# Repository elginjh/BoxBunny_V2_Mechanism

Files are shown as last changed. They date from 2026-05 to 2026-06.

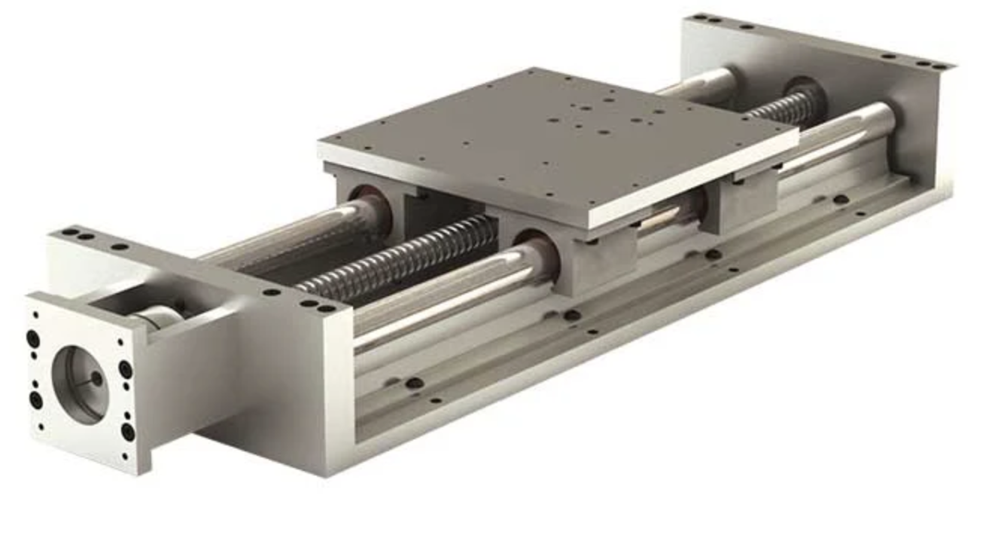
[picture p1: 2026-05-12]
CAD Model/Interim/Sub Assembly/Bottom/Renders/Movement/Ball Screw Driven Linear Rail.png

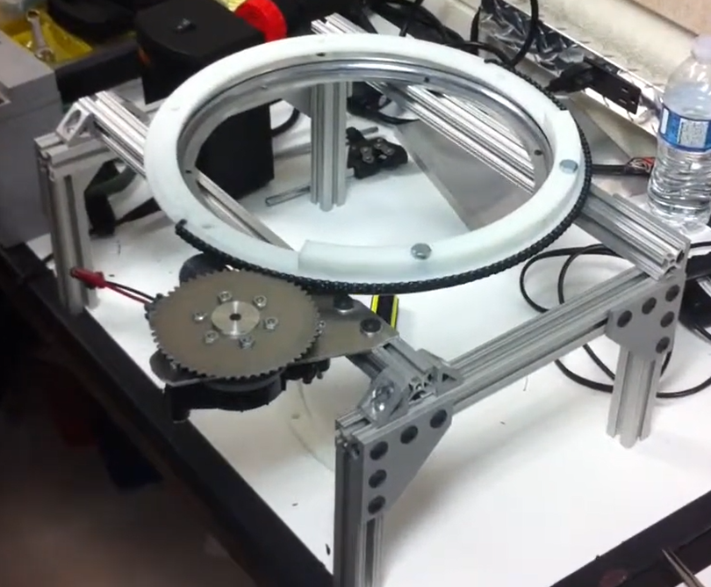
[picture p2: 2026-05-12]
CAD Model/Interim/Sub Assembly/Bottom/Renders/Movement/Lazy Susan Build.png

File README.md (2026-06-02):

# BoxBunny V2 Mechanism: Project Handover Documentation

This document serves as the formal handover reference for the BoxBunny V2 Mechanism repository. It details the directory structure, critical design rationales, and essential system configurations required for subsequent development phases.

## 1. Directory Structure and Repository Navigation

### 1.1 Electrical and Firmware (`ARM_ELECTRICAL_HANDOFF/`)
This directory contains critical documentation and codebase for the control systems, firmware, and electrical routing.
- **`KNOWN_ISSUES_HANDOFF.md`**: Mandatory reading prior to system operation. It documents active hardware and electrical limitations (e.g., ODrive Regen Clamp resistor sizing, 3D printed gear structural limits) and historical defect resolutions to prevent regression. It also outlines essential architectural behaviors, such as Joint-Space Pitch Clamping and "Tactical Walking".
- **`teensy_firmware_V5/`**: Contains the production Teensy 4.0 firmware used for the 200 Hz control loop, CAN bus communication with Damiao motors, and I²C MPU6050 polling. Refer to the internal `README.md` for pin assignments, ROS 2 topics, and micro-ROS payload layouts.

### 1.2 Mechanical Design and CAD Models (`CAD Model/`)
Contains the physical design files and sub-assemblies for the BoxBunny mechanism.
- **`Final/FINAL ASSEM/`**: The primary directory for the overall CAD. Contains the full, latest assembly file (`FINAL ASSEM.asm`), systematically structured into subfolders corresponding to the various subsystems.
- **`Final/Bottom Assembly/v7_fab/`**: Contains the latest production bottom assembly files, logically organized into individual subfolders. The nested `report/` directory contains HTML documentation (`concept-generation.html`, `lift-structure-separation.html`) detailing the engineering rationale for the height adjustment subsystem.
- **`Interim/`**: Contains deprecated V2 iterations and reference sub-assemblies.
- *Note: Various `readme-and-terms-of-use-3d-cad-models.txt` files are included throughout this directory, providing licensing text for third-party COTS components sourced from PARTcommunity/3Dfindit.*

### 1.3 General Project Documentation and Reports (`General Project/`)
Contains legacy V1 project files, procurement details, and comprehensive engineering reports.
- **`Procurement/`**: Contains documentation for all purchased items claimed and selected for this project. Technical specifications are accessible via the provided purchase links or, if unavailable online, stored directly within the `additional tech specs` directory.
- **`Reports/Final Report/Handover - Lower Mechanism FINAL Detailed Reports/`**: Contains the comprehensive final engineering documentation detailing the design, analysis, and specifications for the height adjustment, rotation, and base mechanisms.
- **`Reports/Interim Report/report appendix b/jeanette appendix b.txt`**: A detailed text export of the engineering calculations and concept generation matrices. This is required reading for understanding:
  - **Upper Mechanism:** The justification for the 2DOF (pitch/yaw) actuator, including torque, inertia, and aerodynamic drag calculations for the training sticks.
  - **Lower Mechanism:** The rationale for decoupling the footwork motion into a linear rail (forward/backward) and a slewing bearing (rotation) over omnidirectional wheels, alongside motor sizing and selection matrices.
- **`V1 (EG3301R)/`**: Legacy files from the first iteration of the BoxBunny project.

## 2. Mandatory Pre-Operation Procedures

1. **Review Known Issues:** Prior to motor initialization, operators must review the ODrive Regen Clamp calibration procedures and I²C blocking mitigations detailed in `KNOWN_ISSUES_HANDOFF.md`.
2. **Firmware Verification:** Verify that the Teensy microcontroller is provisioned with **Firmware V5** (`teensy_firmware_V5.ino`). This build contains critical hardware I²C timeouts and failsafes for IMU disconnections to prevent uncontrolled motor oscillation.

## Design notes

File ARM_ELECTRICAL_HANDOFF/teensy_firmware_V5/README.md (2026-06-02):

# Teensy Firmware V5

**Target:** Teensy 4.0 | **IDE:** Arduino IDE + Teensyduino

## What's in this sketch

| Feature | Detail |
|---|---|
| Control loop | 200 Hz unified loop (5 ms period) |
| CAN bus | FlexCAN_T4, 1 Mbps, 4× Damiao DM-J4310-2EC (base IDs 0x01–0x04; command frames 0x101–0x104) |
| IMU | 4× MPU6050 over dual I²C bus (Wire + Wire1, 400 kHz) |
| Height motor | Cytron MDDS10 via PWM (Pin 3) + DIR (Pin 2) |
| ROS 2 | micro-ROS over USB; publishes 21-double `/motor_feedback` payload |

## Feedback payload layout

```
[0..3]  Motor positions (rad)
[4..7]  Motor currents (A)
[8]     CAN RX frame count
[9..20] IMU accel XYZ for each of 4 sensors (m/s²)
```

## Changelog

### V5 Release (I²C Blocking Fix & Failsafe)
- **Hardware I²C Timeouts:** Added `Wire.setWireTimeout(3000, true)` on both I²C buses to prevent the default blocking behavior. If an MPU6050 disconnects or hangs, the bus safely aborts the read after 3ms instead of freezing the 200Hz loop and starving the CAN bus.
- **Sensor State Failsafe:** Introduced a global `imu_healthy` flag that tracks consecutive sensor errors. If an IMU drops offline (e.g. `imu_err_count > 3`), the firmware actively triggers a software override that sets `motors_enabled = false`. This drops the robot into a safe limp state, preventing violent jitter caused by "garbage" 0-value sensor data.

### 2026-04-06 — IMU range fix
- **ACCEL_CONFIG** changed `0x00` (±2g) → `0x18` (±16g)  
- **Conversion divisor** changed `16384.0` → `2048.0`

**Reason:** Empirical readings exceeded 19.62 m/s² (the ±2g saturation ceiling), confirming the sensor was running at ±16g hardware default. The old divisor underscaled all IMU output by 8×.

**After reflashing:** Re-run IMU gravity calibration in the GUI (Calibration tab → Re-calibrate IMU). Strike detection thresholds will need re-tuning — physical strike values will read approximately 8× higher than before.

## Libraries required

- `micro_ros_arduino` (micro-ROS)
- `FlexCAN_T4` (CAN bus)
- `Wire` (built-in — I²C)

## Pin assignments

| Pin | Function |
|-----|---|
| 3 | MDDS10 AN1 — PWM speed |
| 2 | MDDS10 DIG1 — direction |
| 18 / 19 | Wire SDA / SCL (IMU bus 1) |
| 17 / 16 | Wire1 SDA / SCL (IMU bus 2) |
| 13 | LED (micro-ROS status) |

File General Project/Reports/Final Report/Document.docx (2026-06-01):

\section*Two-MountSplit(CenteredHit)

\subsection*Given

[

d=0.20~m, e=0.

]

Let(F_(cap,tip) )and(F_(cap,side) )bethefoamplateauforcecapsfor

tip-on and side-on contact, respectively, and let (γ) be a shock factor.

From the pool-noodle model:

[

F_(cap,tip) ∈[170, 283]~N,

F_(cap,side) ∈[144, 480]~N,

γ= 1.4.

]

The transmitted peak into the arm bracket is bounded by the foam cap:

[

F_(trans) ≈γ min!(F_(cap,tip) , F_(cap,side) ).

]

Conservativeenvelopestoconsider(orientation-dependent):

[

〖{aligned}

\text{Tip-on:}\quad &F_{\text{trans}} \in [1.4\times170,\ 1.4\times283] = [238,\ 396]~\text{N},\\[2pt]

\text{Side-on:}\quad &F_{\text{trans}} \in [1.4\times144,\ 1.4\times480] = [202,\ 672]~\text{N}.

\end{aligned}

\]

\subsection*{Load per Mount for a Centered Hit}

With two mounts and \(e=0\),

\[

F_{\text{hot}} \;=\; \frac{F_{\text{trans}}}{2}.

\]

Hence,

\[

F_{\text{hot}} \in

\begin{cases}

[119,\ 198]~\text{N}, & \text{(tip-on)}\\[2pt]

[101,\ 336]~\text{N}, & \text{(side-on)}\\

\end{cases}

\]

\subsection*{Design Recommendation (per mount)}

Apply a design/safety factor \(SF\) to cover material scatter, aging, and occasional off-center hits:

\[

F_{\text{mount,design}} \;=\; SF \cdot F_{\text{hot,max}}.

\]

Using \(F_{\text{hot,max}} = 336~\text{N}\) (side-on upper bound) and \(SF=2.0\text{--}3.0\):

\[

F_{\text{mount,design}} \approx 0.67\text{--}1.01~\text{kN}.

\]

\paragraph{Suggested spec (per mount):}

\[

\boxed{F_{\text{rated}} \approx 1.0~\text{kN}},\qquad

\text{shear-oriented sandwich/angle type, } 10\text{--}12~\text{mm elastomer, M8 bolts.}

\]

For extra conservatism (to tolerate occasional \(e\neq0\) strikes), select

\(\boxed{F_{\text{rated}} \approx 1.2~\text{kN}}\).

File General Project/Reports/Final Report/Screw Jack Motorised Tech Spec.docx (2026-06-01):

# Screw Jack Motorised Tech Spec

The primary procurement undertaken during this project phase was the Screw Jack, coupled with its compatible motor, which together serve as the driving mechanism for adjusting the robot’s height. There were two design segments that had to be heavily considered for the overall stability of the robot: Telescopic Tubes, and Base Support.

## Technical Information of Driving Mechanism

The height-adjustment mechanism of the robot is implemented using a motorised screw jack driven by a three-phase AC induction motor. The screw jack provides vertical linear motion via a travelling nut, while the motor supplies the rotational input. The system is designed for controlled, bidirectional vertical motion (up/down) with end-of-travel protection using limit switches. Table 1 shows the technical specifications for the screw jack and motor.

Table 1: Screw Jack Assembly Specifications

Component | Parameter | Specification
Screw Jack | Model | HK2T
| Rated lifting capacity (selected) | 300 kg (design requirement)
| Structure type | Travelling nut type
| Nut material | Copper (brass) nut
| Stroke length | 400 mm
| Gear ratio | 1:10 (selected configuration)
| Hoist speed | ~0.70–0.75 m/min
| Estimated travel time (400 mm) | ~32–34 s
| Installation | Vertical mounting, guided by external wear-pad sleeves
Motor | Motor type | Three-phase AC induction motor
| Mounting type | B5 flange mount
| Rated power | 0.37 kW
| Rated speed | 1400 r/min (rpm)
| Rated voltage | 380 V / 220 V (dual voltage)
| Rated current | 1.12 A (380 V, Y) / 1.92 A (220 V, Δ)
| Rated frequency | 50 Hz
| Connection | Y (380 V) / Δ (220 V)
| Protection class | IP54
| Insulation class | Class F
| Motor mass | 6.9 kg

## Control System Design

Electrical power is supplied from a standard 230 V single-phase wall outlet. The incoming power is first routed through basic protective devices (MCB/RCD/fuse) and a main switch to ensure overcurrent and fault protection. This should be split into two branches:

- Branch A (high power): VFD/contactor system → screw jack motor
- Branch B (low voltage): 230V → transformer to lower voltages for other robot components

This keeps motor noise from killing the other electrical components.

A Variable Frequency Drive (VFD) is used to:

- Convert single-phase AC input into three-phase AC output,
- Supply the appropriate voltage and frequency required by the motor,
- Enable forward and reverse motor operation for bidirectional screw jack travel.

Although speed control is not required for this application, the VFD functions as a phase converter and motor starter, enabling compatibility between wall-plug power and a three-phase induction motor.

The VFD drives a 0.37 kW, three-phase AC induction motor mounted via a B5 flange directly to the screw jack input. The motor operates at approximately 1400 r/min under rated conditions.

Rotational motion from the motor is transmitted through the screw jack’s internal reduction gearbox (ratio 1:10), converting high-speed, low-torque input into low-speed, high-torque output suitable for vertical lifting.

The screw jack employs a travelling nut mechanism, which translates rotational input into vertical linear motion with a stroke of 400 mm. The travelling nut is mechanically connected to the robot’s upper structure.

To prevent lateral loading on the screw and nut, vertical motion is constrained using a guided column system consisting of wear pads or guide sleeves. These guides absorb lateral forces arising from user interaction (e.g., punching impacts), ensuring that the screw jack primarily experiences axial loads.

User Interface

Bidirectional motion (UP/DOWN) is commanded electrically via either:

- A reversing cam switch (UP–OFF–DOWN), or
- Two momentary push buttons (UP / DOWN).

End-of-travel Protection

Two limit switches are installed at the upper and lower ends of travel:

- The top limit switch interrupts upward motion at maximum height,
- The bottom limit switch interrupts downward motion at minimum height.

These limit switches are wired into the control circuit to provide automatic stopping and prevent mechanical over-travel, ensuring safe operation of the height-adjustment mechanism.

The height-adjustment actuator is controlled using a single-phase-input variable frequency drive (VFD) configured for external terminal control. Forward and reverse motion are commanded via dedicated digital inputs (M1 and M2) using momentary UP and DOWN pushbuttons. End-of-travel protection is implemented using upper and lower limit switches wired in series with the corresponding direction command. Although normally open limit switches are used in the current prototype, the control logic ensures that motion is inhibited at the travel limits while still allowing reversal away from the end position. The VFD eliminates the need for external reversing contactors and provides integrated motor protection and soft-start capability.

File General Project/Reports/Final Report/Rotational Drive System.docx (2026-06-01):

# Motor Sizing for BoxBunny Rotational Drive System

## 1. Introduction

This report presents the motor sizing basis for the rotational drive system of BoxBunny. The purpose of the rotational axis is to allow the robot body to yaw realistically in response to programmed movement and user interaction, while also remaining mechanically stable when subjected to external punching loads. The motor selected for this axis must therefore satisfy three distinct torque requirements:

1. Acceleration / deceleration torque required to start and stop the rotating mass,
2. Holding / stall torque required to resist external disturbance moments during punching,
3. Continuous torque required to maintain steady rotation against system friction and drag.

A proper motor sizing process must distinguish these torque components clearly, because they correspond to different physical operating conditions. The first is a transient inertial requirement, the second is a peak disturbance requirement, and the third is a long-duration operating requirement. In practice, the final motor and gearbox combination must be selected such that all three conditions are satisfied with an appropriate engineering safety margin.

## 2. Objective

The objective of this analysis is to determine the torque requirements for the yaw rotation system of BoxBunny and to define the basis for selecting a suitable motor-gearbox drive. The report focuses on the following:

- Quantifying the instantaneous torque needed to accelerate and decelerate the robot’s rotating body,
- Quantifying the disturbance torque imposed on the rotational axis under worst-case punching conditions,
- Defining the continuous torque requirement for sustained operation, and
- Presenting a structured torque budget for final motor selection.

## 3. System Description

The rotational axis allows BoxBunny’s upper body or main body assembly to rotate about a vertical yaw axis. This rotation is supported by a slewing ring bearing and driven by a motorised transmission system. During operation, the rotational structure must perform two main functions:

- execute commanded angular motion with acceptable responsiveness, and
- resist uncommand angular displacement caused by user punches on the striking pads.

The yaw axis is therefore not only a motion axis but also a structural disturbance axis. This makes it necessary to size the motor not just for motion performance, but also for static resistance to externally applied moments.

A key design consideration is the definition of the effective yaw axis used in moment calculations. The yaw axis may be approximated as the geometric centreline of the main robot body, such as the central axis of the 8080 aluminium extrusion frame housed within the steel tube, and the effective moment arm is measured relative to the centre of rotation, it being where the striking force comes in contact with the padding. Thus, for final validation:

- axis of rotation should be taken as the centre of the slewing ring / rotational assembly,
- mass properties and lever arms should be verified from the final CAD model.

## 4. Design Basis and Loading Philosophy

The rotational motor must be checked against a hierarchy of operating cases. These are separated below because each one governs a different aspect of motor selection.

### Case 1: Starting & Stopping the rotating mass

When the robot begins rotation or is brought to a stop, the motor must overcome the inertia of the rotating assembly. This produces a transient torque requirement determined by the total rotational inertia and the desired angular acceleration. This is the acceleration/deceleration torque, and it represents the torque needed purely for motion control performance.

Target Values:

Peak Yaw Speed - Target Angular Velocity | 150°/s = 2.618 rad/s = 25 rpm
Yaw Angle | ± 90°

The validated rotational performance target for BoxBunny is 150°/s, which is equivalent to 2.618 rad/s or approximately 25 rpm. Therefore, the angular acceleration must be obtained from the time taken for the rotating base to ramp from rest to the target speed.

[T_instantaneous = α × J]

[α = ∆ω/∆t]

[J = (m⋅r_arm^2)/2]

where:

- (α) = angular acceleration [rad/s^2],
  - (ω) = angular velocity change [rad/s]
  - (t) = acceleration time [s]
- (J) = total mass moment of inertia of the rotating assembly about the yaw axis [kg⋅m^2]
  - (m) = mass [kg]
  - (r_arm) = lever arm radius at which the punching contact meets the padding [m]

For BoxBunny, a 1.0s acceleration time is adopted as the current design assumption. This is a reasonable and defensible preliminary value because it represents a responsive but still mechanically realistic ramp-up for a human-scale rotating robot base. A much shorter acceleration time would impose unnecessarily high transient torque and jerk on the drivetrain, while a much longer acceleration time may make the robot feel sluggish and unresponsive. The 1.0 s assumption therefore provides a balanced basis for preliminary motor sizing until direct experimental ramp-time data is available. Therefore, the angular acceleration required is:

α=ω/t=(2.618 rad/s)/(1 s)=2.618 rad/s^2

The rotational inertia used in this analysis was taken directly from the SolidWorks mass properties of the rotating assembly. The following assumptions were made in this specific inertia-based motor sizing analysis:

- The rotational motion is treated as a single-axis yaw rotation problem.
- The yaw axis is aligned with the output coordinate system’s y-axis in the SolidWorks model.
- The SolidWorks Iyy term represents the relevant rotational inertia for acceleration torque sizing.
- The off-diagonal tensor terms are neglected because cross-axis coupling is assumed to be insignificant for this calculation.
- Full three-dimensional rigid-body dynamics effects are not considered in this stage of analysis.

Therefore, the appropriate inertia term is Iyy from the SolidWorks mass properties output, rather than the full tensor or the principal moments. From the SolidWorks model of the rotating assembly:

J=0.577 kg⋅m^2

∴T_(instant) =α×J=2.618×0.577=1.51 N⋅m

This value therefore represents the instantaneous starting and stopping torque required for the rotating base to reach the validated target speed of 150°/s, or approximately 25rpm, in about 1 second, based on the SolidWorks-derived rotational inertia of the current rotating assembly.

#### Design interpretation

This torque is not normally the dominant continuous operating load, but it is critical for dynamic performance. If the motor cannot provide this torque at the required speed, the robot will feel sluggish, unable to start quickly, or unable to stop accurately. Therefore, this value should be treated as a key minimum transient torque requirement at the transmission output.

### Case 2: Resisting punch-induced external moment

During training, the user may strike the robot’s pad while the robot is stationary or moving. A punch applied at an offset from the yaw axis generates a moment that attempts to rotate the body unintentionally. In the worst-case scenario, the applied force acts in the pure tangential direction, meaning it is perpendicular to the radial line from the yaw axis to the point of contact. This produces the maximum possible moment about the yaw axis:

[T_disturbance = F_design × r_hit]

where:

- (F_design) = design punching force,
- (r_hit) = perpendicular distance from yaw axis to strike location.

This is the holding torque requirement, because the motor-transmission system must resist this moment without being back-driven excessively or losing control of orientation.

### Case 3: Sustained steady rotation

Once the system is rotating at near-constant speed, the torque demand is lower and is governed mainly by friction in the slewing bearing, transmission inefficiencies, seal drag, and any minor imbalance effects. This is the continuous torque requirement.

5. Torque Component 1: Acceleration / Deceleration Torque

The first torque component is the torque required to accelerate and decelerate the rotating mass of the robot body.

5.1 Definition

The inertial torque required to produce angular acceleration is given by:

[T_{accel} = J\alpha]

where:

- (J) = total mass moment of inertia of the rotating assembly about the yaw axis,
- (\alpha) = angular acceleration.

This same torque magnitude is also required in deceleration if the design demands the same stopping performance.

5.2 Current result

From the earlier motion sizing work, the required torque to accelerate or decelerate the rotating mass has been determined as:

[\boxed{T_{accel/decel} = 34.67\ \text{N·m}}]

This value represents the instantaneous starting/stopping torque associated with the intended rotational responsiveness of the system.

5.3 Design interpretation

This torque is not normally the dominant continuous operating load, but it is critical for dynamic performance. If the motor cannot provide this torque at the required speed, the robot will feel sluggish, unable to start quickly, or unable to stop accurately. Therefore, this value should be treated as a key minimum transient torque requirement at the transmission output.

6. Torque Component 2: Holding / Stall Torque Due to Punch Disturbance

The second torque component is the torque required to resist an externally applied punch load at the striking pad.

This is often the most important safety-critical torque requirement because it governs whether the robot can maintain orientation and avoid being violently back-driven during impact.

6.1 Worst-case loading scenario

The worst-case disturbance occurs when the boxer punches the striking pad in a direction that is purely tangential to the rotational path of the robot body. In other words, the punch direction is perpendicular to the radius drawn from the yaw axis to the point of impact. Under this condition, the full force contributes to rotational moment, and the torque is maximised.

This is more severe than a punch directed radially toward the centre, because a radial force produces little or no moment about the yaw axis. Therefore, for conservative motor sizing, the tangential loading case should be used.

6.2 Choice of yaw axis reference

For this disturbance torque calculation, the reference axis should ideally be the actual yaw rotation axis of the mechanical assembly, i.e. the centre of the slewing ring or the true rotational centre of the robot structure. In practical early-stage calculations, the centreline of the main structural body may be used as an approximation if the robot is sufficiently symmetric. However, if the pad location, frame mass distribution, or striking structure is significantly offset, then the final moment arm must be taken from the CAD model.

Accordingly, the final report should state that the disturbance torque is to be evaluated using:

- the actual rotation axis of the system, and
- the perpendicular offset from this axis to the strike point in the worst-case pose.

6.3 General equation

The disturbance torque is:

[
T_{disturbance} = F_{design} \times r_{eff}
]

where:

- (F_{design}) = design impact force,
- (r_{eff}) = effective perpendicular moment arm from yaw axis to strike point.

6.4 Basis of the 2.7 kN design force

The disturbance torque analysis uses a 2.7 kN design punch force. This should be presented not merely as an arbitrary number, but as a conservative design load derived from the project’s punch load analysis philosophy.

The rationale for using this design force is that the robot must not be sized only for average or casual punch levels. Instead, it should be checked against a deliberately conservative upper-bound load representing severe user interaction and dynamic amplification.

The 2.7 kN value should be described as a design-level impact load adopted for structural and rotational sizing under worst-case demonstration or training conditions. The purpose of this value is to account for:

- strong user punches,
- dynamic impact effects rather than purely static equivalent loading,
- uncertainty in strike direction and contact location,
- variability between users, and
- the need for robustness during demonstrations and repeated public use.

In engineering terms, this means the rotational axis is being sized against a peak disturbance event, not an average operating event. The 2.7 kN load is therefore suitable for conservative torque and structural verification, provided that the same design basis is used consistently across the wider robot design.

6.5 Disturbance torque expression for BoxBunny

Using the 2.7 kN design load, the holding torque requirement becomes:

[
T_{disturbance} = 2700 \times r_{eff}
]

where (r_{eff}) is in metres and the resulting torque is in N·m.

For example:

- if (r_{eff} = 0.20\ \text{m}), then (T_{disturbance} = 540\ \text{N·m}),
- if (r_{eff} = 0.25\ \text{m}), then (T_{disturbance} = 675\ \text{N·m}),
- if (r_{eff} = 0.30\ \text{m}), then (T_{disturbance} = 810\ \text{N·m}).

This shows clearly that the disturbance torque can easily become much larger than the acceleration torque, depending on strike radius. Therefore, the rotational transmission must be evaluated carefully for:

- back-drivability,
- gearbox output holding capacity,
- torsional stiffness,
- shock tolerance, and
- allowable tooth load in the drive pinion and slewing bearing gear mesh.

6.6 Design implication

This disturbance torque is the torque the system must resist at the output, not merely the nominal motor shaft torque. In practice, whether the motor itself must fully resist this load depends on the drivetrain architecture. For example:

- a high-ratio gearbox may reduce back-driving,
- a worm or self-locking arrangement may help resist external motion,
- a brake-equipped motor may hold position more effectively, and
- a servo system with active control may still require mechanical shock protection.

Therefore, the report should distinguish between motor torque capability and system holding torque capability at the output stage.

7. Torque Component 3: Continuous Torque for Steady Rotation

The third torque component is the torque required to maintain rotation once the robot is already moving at approximately constant speed.

7.1 Definition

At steady speed, angular acceleration is approximately zero, so inertial torque is no longer the dominant requirement. Instead, the motor must overcome resistive torques such as:

- slewing bearing rolling friction,
- seal drag,
- gear mesh friction,
- transmission efficiency losses,
- cable drag or routing resistance,
- minor imbalance or misalignment effects.

Thus,

[
T_{continuous} \approx T_{friction} + T_{drag}
]

7.2 Current status

At present, this value is to be filled in using the friction torque determined from the slewing bearing and the associated drive system losses. This should ideally be obtained from:

- bearing manufacturer data,
- estimated friction torque from load condition,
- gear efficiency assumptions, and
- experimental verification if available.

7.3 Design implication

This torque is important because it governs:

- motor thermal loading,
- continuous current draw,
- long-duration energy consumption, and
- feasibility of repeated operation without overheating.

Even if the acceleration torque or disturbance torque is much larger, the continuous torque requirement is still essential for correct motor rating because it determines the motor’s sustained duty capability.

8. Overall Torque Budget and Selection Logic

The motor selection should not be based on a single torque figure. Instead, the rotational system should be sized against the three torque demands discussed above.

8.1 Summary of torque components

Torque component | Meaning | Current value / form | Design role
Acceleration / deceleration torque | Torque to start and stop rotating mass | 34.67 N·m | Transient motion requirement
Holding / stall disturbance torque | Torque to resist punch-induced moment | (2700 \times r_{eff}) N·m | Peak disturbance / anti-backdrive requirement
Continuous torque | Torque to maintain steady rotation against friction | To be determined | Thermal / sustained operation requirement

8.2 Governing condition

In most realistic cases for BoxBunny, the holding/disturbance torque is likely to govern the output-stage sizing, because a high punch force acting at a moderate radius can produce a very large moment. Meanwhile:

- the 34.67 N·m value governs whether the robot can rotate responsively, and
- the continuous torque governs whether it can operate sustainably.

Therefore, the final drive selection must satisfy all three of the following:

1. Output torque greater than 34.67 N·m for acceleration/deceleration,
2. Output holding capacity greater than the worst-case disturbance torque, and
3. Motor continuous rating sufficient for the predicted friction torque and duty cycle.

9. Engineering Recommendations for Final Design

Based on the current analysis, the following recommendations should be adopted in the next design stage.

9.1 Verify rotational inertia from CAD

The 34.67 N·m acceleration torque should be retained as the current design value, but the underlying rotational inertia should be verified directly from the latest SolidWorks assembly mass properties. Any major shift in component mass or radius may significantly affect this value.

9.2 Finalise the effective disturbance lever arm

The most important unresolved quantity in the holding torque analysis is the effective moment arm (r_{eff}). This must be measured from the true yaw axis to the strike location for the worst-case body pose. The final disturbance torque should then be stated numerically in N·m, rather than left as a symbolic expression.

9.3 Use drivetrain-level sizing, not motor-only sizing

The disturbance event should be treated as an output-side torque demand on the whole rotational drivetrain. It is not sufficient to compare this directly to nominal motor torque without considering:

- gearbox ratio,
- gearbox efficiency,
- allowable reflected load,
- back-drivability,
- brake or locking features,
- tooth capacity of pinion and slewing gear,
- shock loading and torsional compliance.

9.4 Determine continuous friction torque experimentally if needed

If manufacturer friction torque data for the slewing ring is not available, the steady torque should be measured experimentally by rotating the unloaded and loaded assembly at low speed and estimating the resisting torque. This will give a much more realistic basis for motor continuous rating.

9.5 Include safety margin in final motor selection

Because the robot is subject to repeated impact loading and demonstration use, the final selected drive should include a practical safety margin above the calculated minimum requirements. This is especially important for shock resistance and durability.

10. Conclusion

The rotational drive motor for BoxBunny must be sized using a structured three-part torque framework rather than a single nominal torque value.

First, the system requires an acceleration/deceleration torque of 34.67 N·m, which represents the instantaneous torque needed to start and stop the rotating body according to the desired dynamic response. This governs motion responsiveness.

Second, the system must resist a holding or stall torque caused by punch-induced disturbance loading. Under the worst-case condition, where the user punches tangentially to the robot’s rotational path, the full punch force contributes to moment about the yaw axis. Using the adopted 2.7 kN design force, the disturbance torque is expressed as:

T_{disturbance} = 2700 \times r_{eff}

This is likely to be the dominant output-side torque requirement and is critical for preventing unintended back-driving of the rotational axis.

Third, the motor must also satisfy the continuous torque requirement for steady rotation, which is governed by slewing bearing friction and drivetrain losses. This value remains to be finalised from bearing friction data or experiment.

Overall, the final rotational drive selection for BoxBunny must satisfy all three criteria: transient inertial torque, peak disturbance holding torque, and continuous steady-state torque. Of these, the punch-induced disturbance torque is expected to be the most severe condition for the output-stage drivetrain, while the acceleration torque determines motion performance. The final report should therefore proceed by measuring the true strike radius from the completed CAD model, computing the numerical disturbance torque, estimating continuous friction torque, and then selecting a motor-gearbox system with sufficient output torque, holding capacity, and durability for repeated real-world boxing interaction.

11. Items to Insert Once Final Values Are Confirmed

The following items should be updated in the final issued version of the report:

1. Actual rotational inertia (J) from SolidWorks,
2. Actual angular acceleration (\alpha) used to obtain 34.67 N·m,
3. Actual effective punch radius (r_{eff}),
4. Final numerical disturbance torque in N·m,
5. Slewing bearing friction torque / continuous torque estimate,
6. Gearbox ratio and efficiency,
7. Final selected motor and output torque rating.

# Moment of Inertia (J) of Rotating Mass on SolidWorks

Mass properties of v6_assem rotating mass

Configuration: FULL Min Height 150cm

Coordinate system: -- default --

Mass = 63535.07 grams

Total weld mass = 445.66 grams

Volume = 16984616.84 cubic millimeters

Surface area = 4476617.02 square millimeters

Center of mass: ( millimeters )

X = 1.92

Y = 614.45

Z = -0.10

Principal axes of inertia and principal moments of inertia: ( grams * square millimeters )

Taken at the center of mass.

Ix = (-0.01, 1.00, 0.00) Px = 576407773.06

Iy = (-1.00, -0.01, 0.05) Py = 9466998849.06

Iz = ( 0.05, 0.00, 1.00) Pz = 9470702934.86

Moments of inertia: ( grams * square millimeters )

Taken at the center of mass and aligned with the output coordinate system. (Using positive tensor notation.)

Lxx = 9466730210.63 Lxy = -49598479.02 Lxz = -184465.04

Lyx = -49598479.02 Lyy = 576684981.16 Lyz = 2111384.54

Lzx = -184465.04 Lzy = 2111384.54 Lzz = 9470694365.18

Moments of inertia: ( grams * square millimeters )

Taken at the output coordinate system. (Using positive tensor notation.)

Ixx = 33454630563.07 Ixy = 25237219.78 Ixz = -196325.52

Iyx = 25237219.78 Iyy = 576919050.64 Iyz = -1690384.97

Izx = -196325.52 Izy = -1690384.97 Izz = 33458827582.04

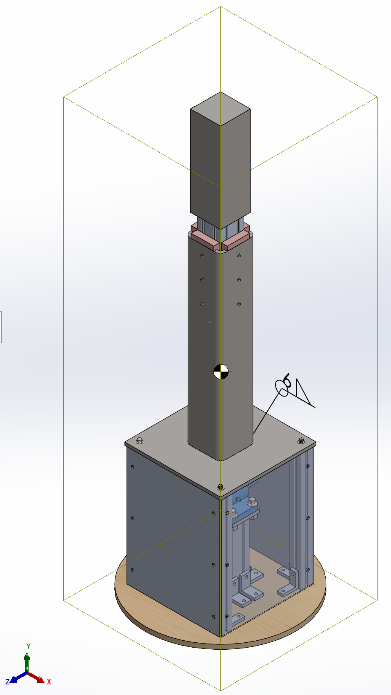
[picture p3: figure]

Since the base rotates about the vertical axis, the moment of inertia is taken at the output coordinate system. The yaw axis of the rotating base is aligned with the output coordinate system’s y-axis.

J=I_(yy) =576919050.64 g⋅mm^2 =0.577 kg⋅m^2

# Load Analysis

## Punch Force Modelling

A boxing punch does not apply a constant force over time. Instead, the force-time profile is highly transient, with a short, sharp peak that lasts only a few milliseconds. Designing the robot directly from this instantaneous peak value would be overly conservative, because most structural and actuation components (such as bearings, linear rails and screw jacks) are specified in terms of equivalent or average working loads rather than isolated spikes.

In addition, measured punch forces depend strongly on context. During real matches, boxers throw a mix of jabs, set-up punches and full-power shots; in contrast, laboratory studies often record deliberate maximal punches delivered under controlled conditions. The resulting values represent different parts of the same distribution and must be interpreted carefully when used for design.

For BoxBunny, we therefore distinguish between:

- a characteristic training load, representing a strong but realistic punch from our target users during regular use; and
- a structural design load, representing a conservative upper bound that the main structure must withstand without failure.

This hierarchy allows the robot to remain realistic and appropriately sized, while still maintaining a clear safety margin against rare, harder-than-average impacts.

### Reference Punch Forces from Literature

Published measurements of boxing punches report a wide range of forces, depending on athlete level, measurement method and whether average or maximal punches are considered. Pierce et al. directly instrumented gloves during six professional boxing matches and reported mean punch forces of approximately 0.9 – 1.2 kN per boxer, with only 5.3% of punches exceeding 2.0 kN, 1.1% exceeding 3.0 kN, and a very small number of outliers above 4.0 kN (maximum ≈ 5.3 kN) (Pierce, Reinbold, Lyngard, & Goldman, 2007). These values represent the average of all punches thrown in a bout (jabs, set-ups, partial-power shots), not deliberate maximum efforts.

In contrast, laboratory studies in which trained boxers deliver intentional maximal straight punches report substantially higher peak forces. Boxing Science summarises such work by noting that punching forces in amateur boxing are around 2.5 kN, corresponding to roughly 3.5 times body weight for a 70 kg athlete (Boxing Science, 2021). This is consistent with a recent experimental study by Xu et al., where university-level boxing athletes produced backward straight punches with mean impact forces of 3.96 ± 0.45 times body weight; for the reported body masses (~64 kg), this corresponds to peak forces on the order of 2.5 kN (Xu, Sun, & Zhu, 2025). Elite Olympic boxers can generate even higher values: one study reported average peak straight-punch forces of approximately 3.4 kN, with some punches exceeding 4 kN when striking a headshot (Walilko, Viano, & Bir, 2005).

In summary:

- ~1.0 kN – typical average in-fight punch force across all punches (professional bouts).
- ~2.5 kN – typical peak force of a deliberate maximal straight punch from trained amateurs / high-level athletes.
- ~3.4 kN and above – maximal straight punches from elite Olympic-level boxers.

### Selected Characteristic and Design Punch Loads

BoxBunny is intended for recreational and amateur users in commercial gyms, rather than heavyweight professionals or Olympic-level athletes repeatedly delivering KO-class punches to a static head target. The design assumptions are therefore anchored around the amateur / high-level athlete range, while remaining above the average in-fight forces reported for professionals.

We first define a characteristic amateur punch force:

Fchar = 1.8 kN

This value is taken as a strong but realistic training punch for our target user group as it lies well:

- above the ≈ 1.0 kN average in-fight force reported in professional matches, and
- below the ≈ 2.5 kN maximal peaks measured for trained amateur / university-level boxers,

To obtain a conservative structural design load, we apply a combined design factor of 1.5 to account for the impulsive nature of punching and possible short-duration amplification relative to the nominal average, and user-to-user variability, modelling simplifications and manufacturing tolerances.

General Recommendations (https://safetyculture.com/topics/factor-of-safety)

Applications | Factor of Safety – FOS –
For use with highly reliable materials where loading and environmental conditions are not severe and where weight is an important consideration | 1.3 – 1.5
For use with reliable materials where loading and environmental conditions are not severe | 1.5 – 2
For use with ordinary materials where loading and environmental conditions are not severe | 2 – 2.5
For use with less tried and for brittle materials where loading and environmental conditions are not severe | 2.5 – 3
For use with materials where properties are not reliable and where loading and environmental conditions are not severe, or where reliable materials are used under difficult and environmental conditions | 3 – 4

This gives:

Fdesign = Fchar × 1.5 = 1.8 kN × 1.5 = 2.7 kN.

The design load of 2.7 kN sits slightly above the ≈ 2.5 kN peak forces reported for trained amateurs and high-level boxing athletes yet remains below the more extreme values observed in Olympic-level or knockout punches. It therefore represents a conservative upper bound appropriate for BoxBunny’s intended use. Table 1 summarises the adopted punch force levels and their roles in the design.

Table 1: Design Load Summary of Punch Forces set for BoxBunny.

Description | Symbol | Value | Basis/Interpretation | Primary Use in Design
Average in-fight punch (professional bouts) | – | ≈ 1.0 kN | Mean force across all punches (jabs, set-ups, power shots); not necessarily maximal | Context only (benchmark for typical match-level loading)
Peak straight punch (trained amateur / high-level athlete) | – | ≈ 2.5 kN | Maximal straight punch under lab conditions from trained amateurs / university-level boxers | Target range for “strong” gym-level punches
Characteristic amateur training punch | F_(char) | 1.8 kN | Strong but realistic punch for BoxBunny target users; between 1.0 kN match average & 2.5 kN maxima | Repeated-load estimates, serviceability checks
Structural design punch load | F_(design) | 2.7 kN | Fchar × 1.5 - combined factor for impact effects & user / modelling uncertainty | Sizing of all structural load paths and global stability

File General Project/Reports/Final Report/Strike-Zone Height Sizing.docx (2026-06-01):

# Strike-zone Height Sizing

Based on pilot measurements from four members of various skill level, the robot’s strike-zone geometry was sized using a ratio-based normalisation approach. For each participant of height H , the preferred strike heights for the head and torso were recorded ( h_(head) ,h_(torso) ) and converted into dimensionless ratios r_(head) =h_(head) /H and r_(torso) =h_(torso) /H . This method allows the preferred striking locations to be scaled to different user statures, while preserving body proportions. Across the four samples, the mean ratios were found to be r_(head) ≈0.921 and r_(torso) ≈0.711 , which were used as baseline targets for defining the head and torso strike-zone locations over the intended user range.

The robot’s overall height adjustment is defined from the ground to the top of the robot head, and is constrained to 150–190 cm, corresponding to the screw-jack stroke of 400 mm. As the lift mechanism translates the head and torso targets together (single-DOF motion), the vertical separation between the head and torso contact points is fixed by design. From the measured data, the head–torso centre spacing for each participant is s_i =h_(head,i) -h_(torso,i) . This spacing was observed to vary between 28–40 cm, with an overall mean of approximately 34 cm. Therefore, the robot’s head and torso strike-zone centres were finalised to have a fixed vertical separation of ~34 cm, which represents a reasonable average proportion while staying within the empirical range of human preferences measured in the pilot group.

Finally, because the head and torso targets move together (no independent adjustment), the design accounts for inter-user variability by sizing the strike-zone pads to be sufficiently tall rather than introducing extra adjustment features. In practice, this means the pads are designed as “zones” (not single points), so that users of different proportions can still experience a realistic and hittable target even when their individual preferred head/torso landmarks differ slightly from the robot’s fixed geometry. This approach maintains mechanical simplicity (single screw-jack height adjustment) while ensuring usability across the intended 150–190 cm operating range.

Predicted strike heights at 150 cm and 190 cm (by participant ratios)

Participant ratio used | Head @ 150 (cm) | Torso @ 150 (cm) | Head @ 190 (cm) | Torso @ 190 (cm)
Girl 1 | 129.0 | 92.4 | 163.4 | 117.0
Girl 2 | 137.3 | 114.8 | 174.0 | 145.4
Guy 1 | 143.2 | 109.3 | 181.4 | 138.5
Guy 2 | 143.1 | 110.1 | 181.2 | 139.5

Design Envelope Summary (min/mean/max across 4 samples)

Target | @ 150 cm user (min/mean/max) | @ 190 cm user (min/mean/max)
Head strike height | 129.0 / 138.1 / 143.2 | 163.4 / 175.0 / 181.4
Torso strike height | 92.4 / 106.6 / 114.8 | 117.0 / 135.1 / 145.4

- At 150 cm: head 138.1 cm, torso 106.6 cm
- At 190 cm: head 175.0 cm, torso 135.1 cm
- 150cm: Head-torso diff = 138.1-109.6=28.5 cm
- 190cm: Head-torso diff = 175-135.1=39.9 cm
- OVERALL: Head-Torso Center Length = 28 - 40 cm (avg = 34cm)

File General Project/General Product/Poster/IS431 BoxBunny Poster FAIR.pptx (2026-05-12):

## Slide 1

BoxBunny:
An Intelligent Boxing Trainer

Muhammad Zakir Haziq | Engineering Science Programme
Ng Jun Hao, Elgin | Engineering Science Programme
Sim Yu Jeanette | Engineering Science Programme
Muthukumaran Yogeeswaran | Engineering Science Programme

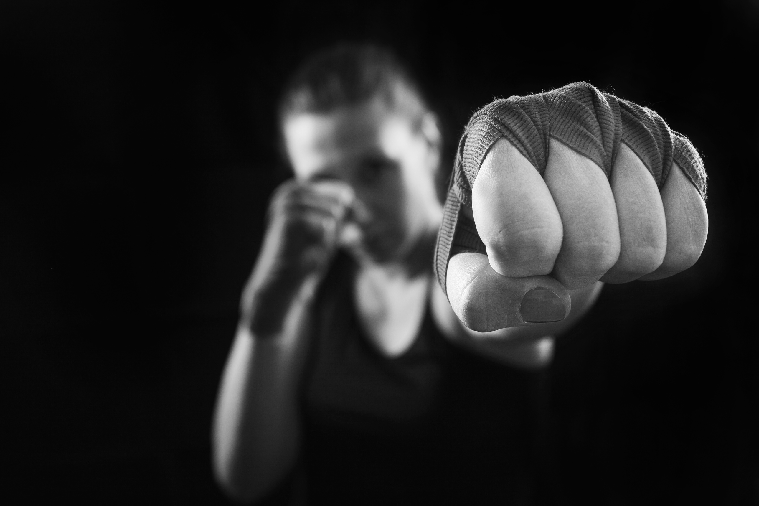
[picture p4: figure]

"How might we design an intelligent boxing training system that can dynamically & safely strike users while assisting coaches in guiding, monitoring, & sustaining boxer development both during & beyond training sessions.”

DESIGN STATEMENT

Contact Points

Polyethylene Foam punching contact points so boxers can punch & get punched without injury

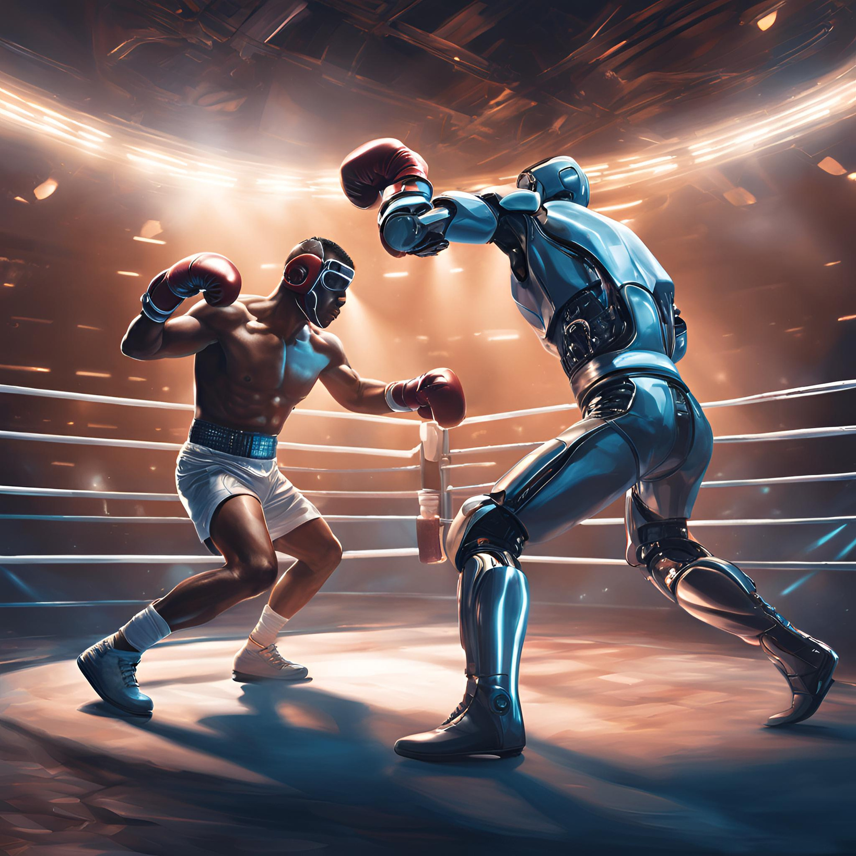
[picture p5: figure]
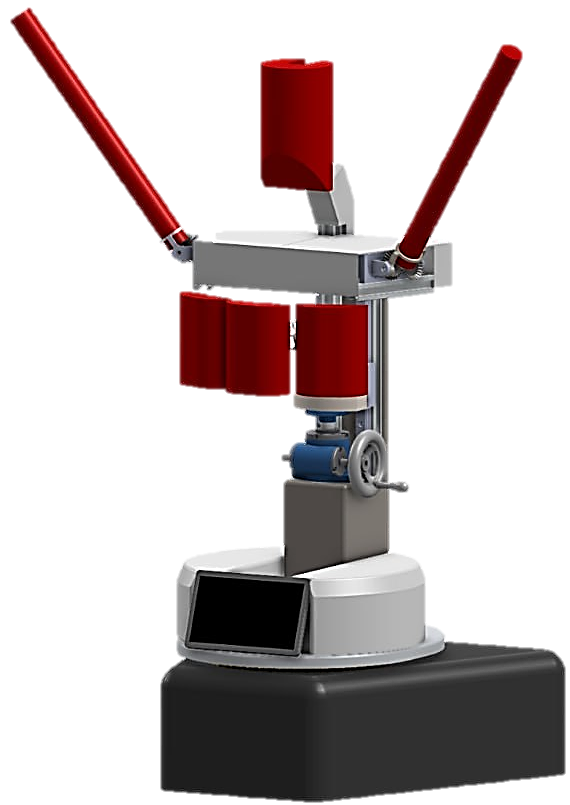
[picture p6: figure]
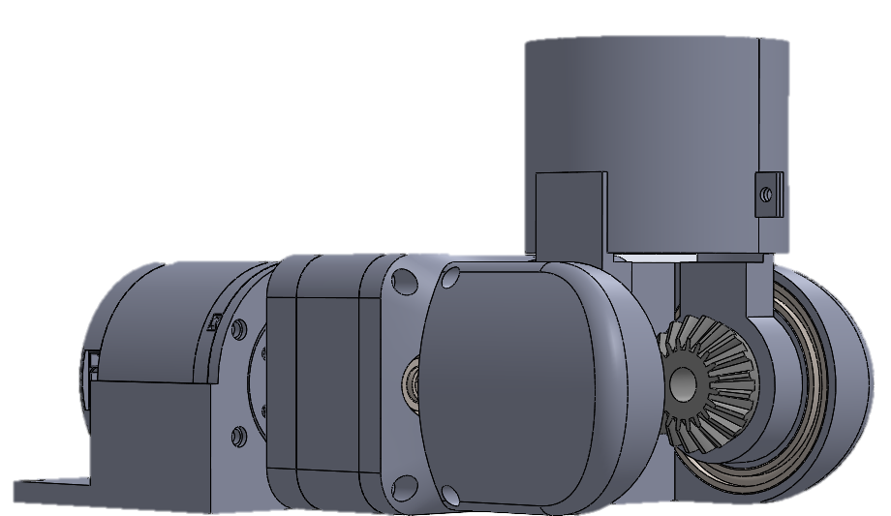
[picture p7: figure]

Arm Actuation

2 Degree-of-Freedom arm-mount that replicates training with boxing sticks used in training

Height Adjustment

Height-adjustable to accommodate boxers of varying heights

Footwork Mechanism

Rotating base to pivot along a single axis for enhanced footwork training

of boxers struggle to stay consistent when progress feels slow or unclear

12/20

of boxers face unreliable or unsuitable sparring partners

44%

of boxers fear high risk of injury during training

36%

Engineering Design and Innovation Centre
Block E2A #04-05
5 Engineering Drive 2
Singapore 117579

PROBLEM

Robot Intelligence

AI Brain with capabilities of LLM Coaching and Computer Vision to increase adaptability and make trainings insightful

KEY FEATURES

Sparring Partner: Reads and adaptively reacts to your attacks and defense!

Punch Combinations: Master your way up to 50 combinations even up from beginner level!

Performance: Test your power, stamina & reaction time with BoxBunny!

Innovation & Design Programme

Website:
https://cde.nus.edu.sg/edic/

Email:
idp-query@nus.edu.sg

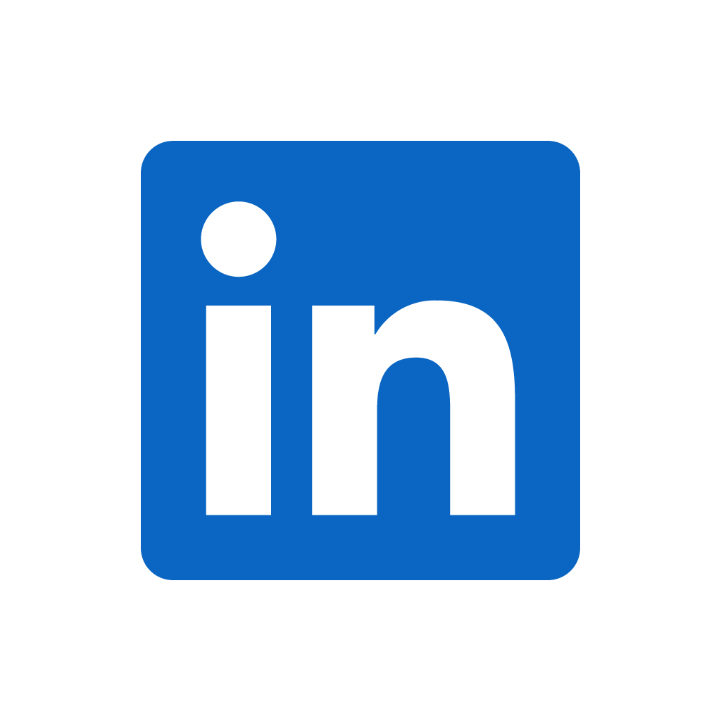
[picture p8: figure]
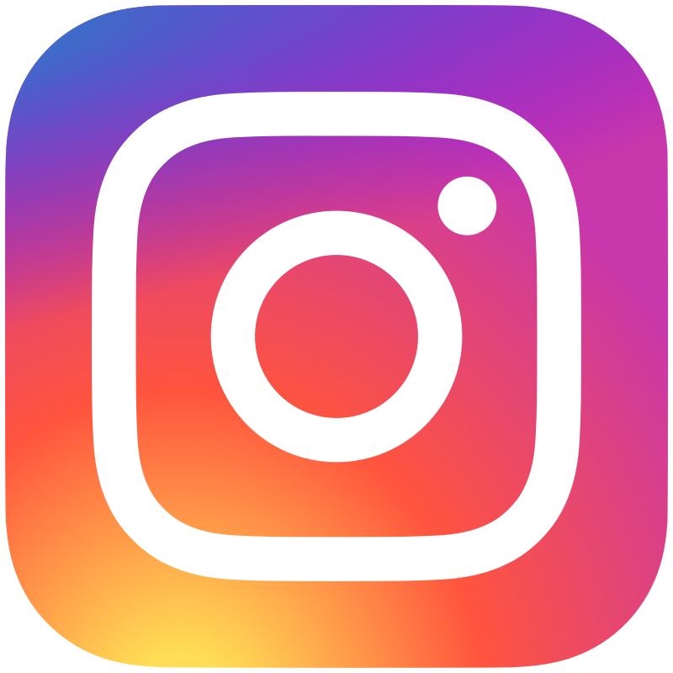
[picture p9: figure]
Instagram - Wikipedia

NUS Innovation & Design Programme

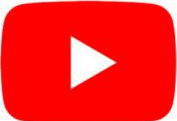
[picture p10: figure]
YouTube is getting a new logo every week this month – here&#39;s why | Creative Bloq
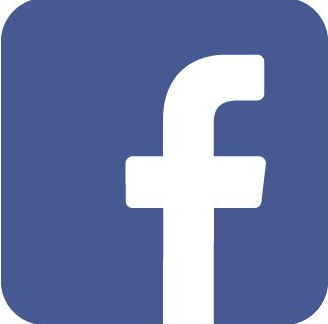
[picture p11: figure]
Facebook Icon Logo Vector (.EPS) Free Download | Facebook icon vector, Facebook icons, Facebook logo png

nusidp

NUS iDP

nusidp

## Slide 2

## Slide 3

COVID-19

LIMITED ACCESS TO TRAINING OPTIONS

RELIANCE ON HOME-BASED SOLUTIONS

NEED FOR FLEXIBLE, INNOVATIVE SOLUTIONS FOR BOXING TRAINING

CONTEXT

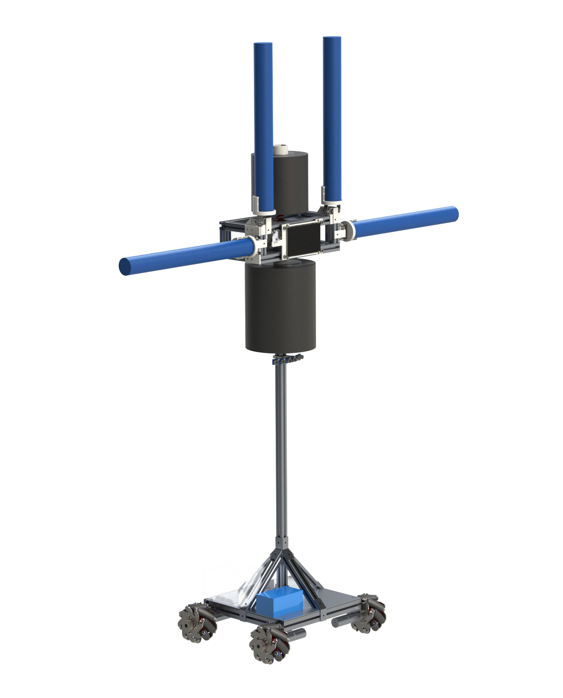
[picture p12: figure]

BoxBUNNY: for boxers-in-development!

IMMERSIVE AND ENRICHING

PROGRESSIVE AND PERSONALISED

EASILY ACCESIBLE!

Ramie Lim Rui Min | Mechanical Engineering
Muhammad Zakir Haziq | Engineering Science
Sim Yu Jeanette | Engineering Science
Mageshkumar Kirubasankar | Mechanical Engineering

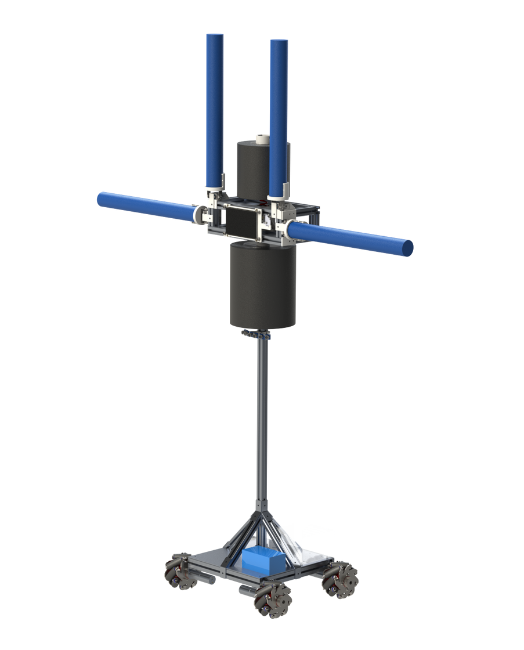
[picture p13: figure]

Processor

AI-driven algorithms to spar with you in real time

Touchscreen

Full control over training modes and combos

Detects your punches and reacts accordingly

Camera

Ultrasonic Sensors

Tracks your movements and moves to follow you

Soft Contact Points

Reduces injury risk to users

TECHNICAL SPECIFICATIONS:

Display

ASPECT

BOXBUNNY

7" IPS (1024x600)
Capacitive Touch

Battery Life

Weight

Size

5 hrs

35 kg

0.4m (L) x 0.4m (W)
x 1.75m (H)

Training Area Size

Camera Tracking Speed

Holding Torque of Arms

4 sqm

60 fps (16.7 ms)

3.4 Nm

Speed of Arms

Speed of Wheels

0.11 sec/60° (no load)
0.13 sec/60° (full load)

1.46 m/s

CURRENT SOLUTIONS?

BOXING CLASSES DON’T ACCOMMODATE TO VARYING SKILL LEVELS

TRAINING WITH ANOTHER PERSON IMPOSES INJURY RISKS

PERSONAL TRAINERS ARE LIMITED AND EXPENSIVE

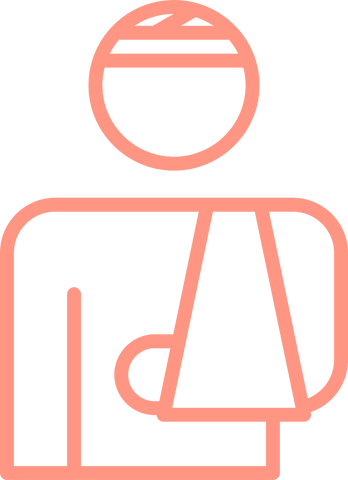
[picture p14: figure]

Mecanum Wheels

Enhanced maneuverability ideal for dynamic environments

KEY FEATURES

  - COMBO MODE
Personalised training for your punching combinations

  - SPAR MODE
Safe & Intelligent sparring partner to test your reflexes + sparring skills

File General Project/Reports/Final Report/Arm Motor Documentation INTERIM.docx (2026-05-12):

# 1. Motor Documentation

## 1.1. Degree of Motion

Robotic arms are typically engineered to enable movement along and rotation about multiple axes, which often necessitates the integration of several motors or actuators along the length of the arm. To avoid implementing unnecessarily complex systems solely to achieve specific striking motions, we consulted our padwork research to identify the required strike types. Our analysis determined that the essential movements about the joint are pitch and row, which can be accomplished with two motors providing these two degrees of motion.

## 1.2. Joint Design (Interim)

We have drawn inspiration from the following video (https://youtu.be/rP8Si_qXkzU) and selected a gear rail system for our design. This approach eliminates the need to mount a motor directly onto the moving arms; however, it introduces additional complexity due to the incorporation of a bevelled gear to facilitate pitch adjustment.

Using Solidworks, a 3D model of the design was created and iterated through.

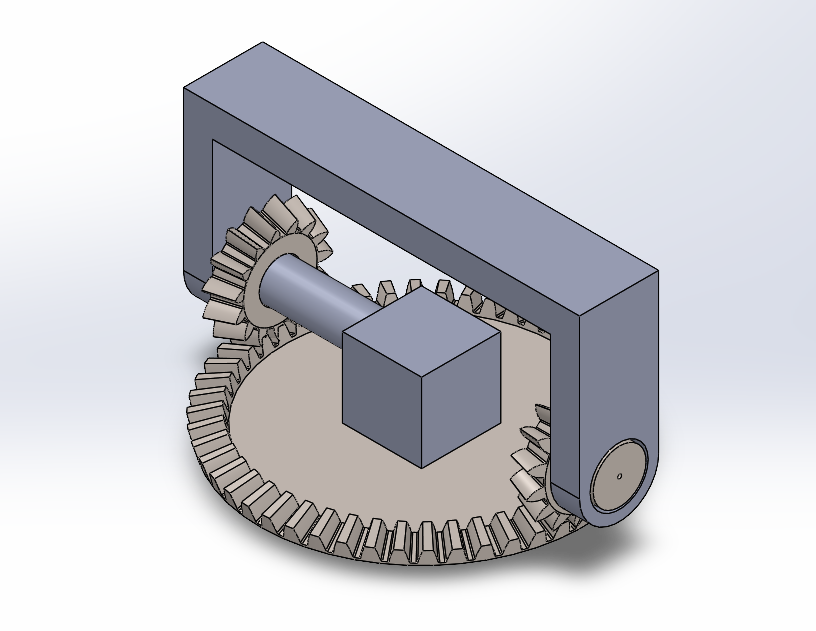
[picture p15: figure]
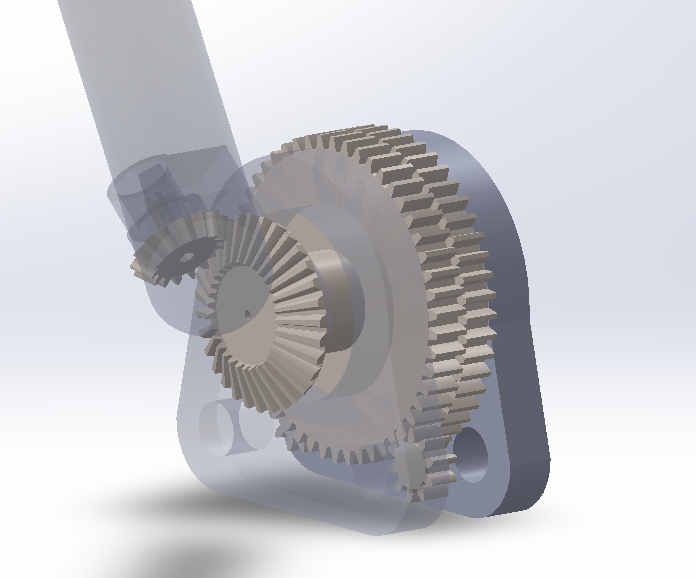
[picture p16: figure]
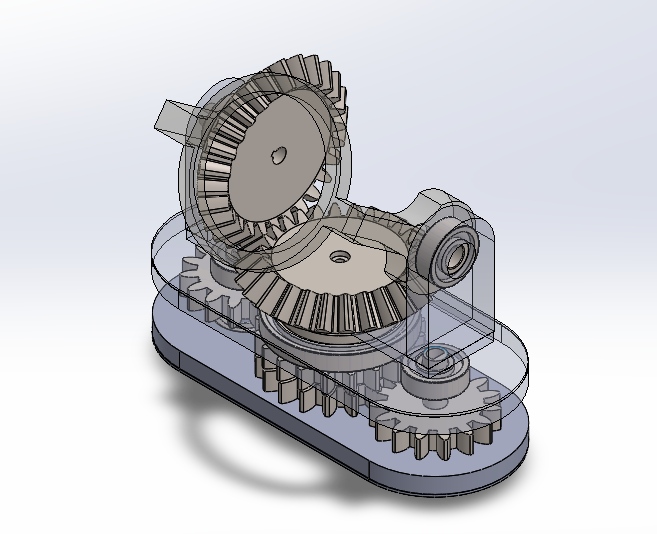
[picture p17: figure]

Label

Iterating through these designs provided insights into aspects of considerations when designing 3D parts. Parts not only need to fit, how the parts are eventually connected is also an important consideration during the design process.

### 1.2.1. Design Validation (Interim)

To valid that our design is truly able to execute the desired strikes, the final iteration was 3D printed using PLA filament. The joints provided the necessary degrees of freedom to achieve the desired strikes.

### 1.2.2. Design Considerations

During the interim presentation, our invigilator commented on two potential issues, backlash and damage due to impact.

Backlash is a common problem faced with gears where gaps within the teeth of the gears creates a lack of motion due to slackness when the motors reverse in direction. To reduce the amount of backlash, we have considered various options. Firstly, backlash can be reduced by decreasing the size of the teeth as an effort to reduce the gaps. Additionally, opting for helical gears would provide a more consistent pressure on the gears when rotating due to the slanted teeth on the gears. Alternatively, the gears can be replaced with timing belts for better accuracy and a reduction to backlash.

Damage to motors from impact is often caused by a sudden stop experienced by the motors. If the arm joint is not designed to be flex or bend during impact, the resistance will feedback into the gears and ultimately the motors. In the previous box bunny, the arm joints were directly mounted to servo motors. When subjected to impacts to the arm joints, the gears within the servo motors often wear down and break. Replacing the motors with brushless DC motors would help improve motor longevity as the motors do not rely on gears and can freely spin when pressure is exerted onto the motors. As we also required accuracy when rotating our joints, the motor control must also be precise and has internal feedback loop for position control.

## 1.3. Motors

Brushless DC motors are often found commonly in drones and RC cars. These motors are designed specifically to spin a wheel or propeller at a certain speed. They are typically controlled with an electronic speed controller (ESC) and which prioritize high RPM, however it generates lower torque at slower speeds. To ensure that the torque the motor can achieve is consistent at all speeds, Field Oriented Control (FOC) provide efficient control and more consistent torque. To achieve an efficient control of the motors, precise feedback of the motor position must be provided via an encoder attached to the motor.

### 1.3.1. Controller

We have selected the Odrive V3.6 and a 360KV drone motor as our initial testing set up.

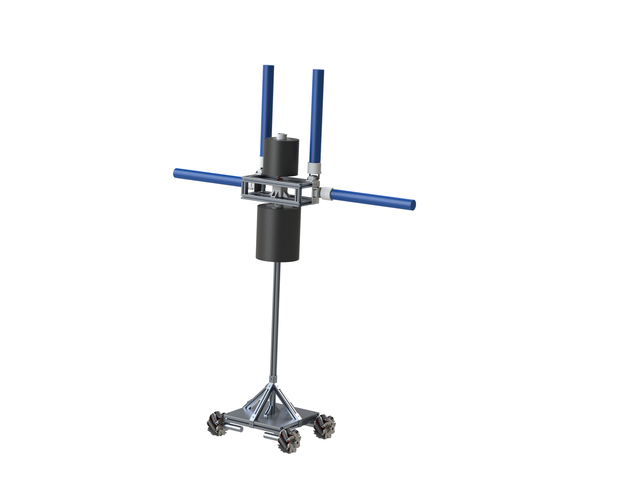
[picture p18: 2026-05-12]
General Project/V1 (EG3301R)/General - EG3301R - Box Bunny/Boxbunny Detailed Model/Renders/Showcase/With Electronics/Mirror View.png

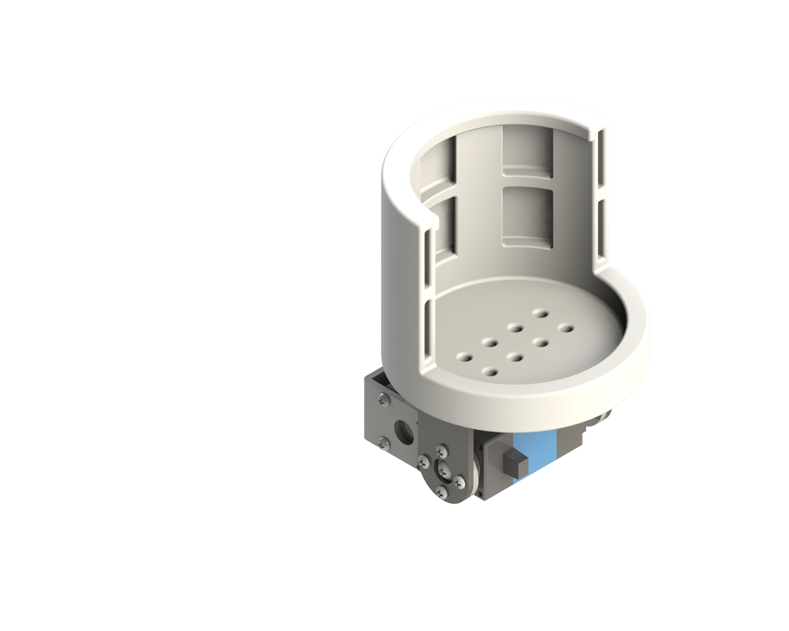
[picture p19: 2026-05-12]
General Project/V1 (EG3301R)/General - EG3301R - Box Bunny/Boxbunny Detailed Model/Renders/Final Report/Arm Foam Holder.png

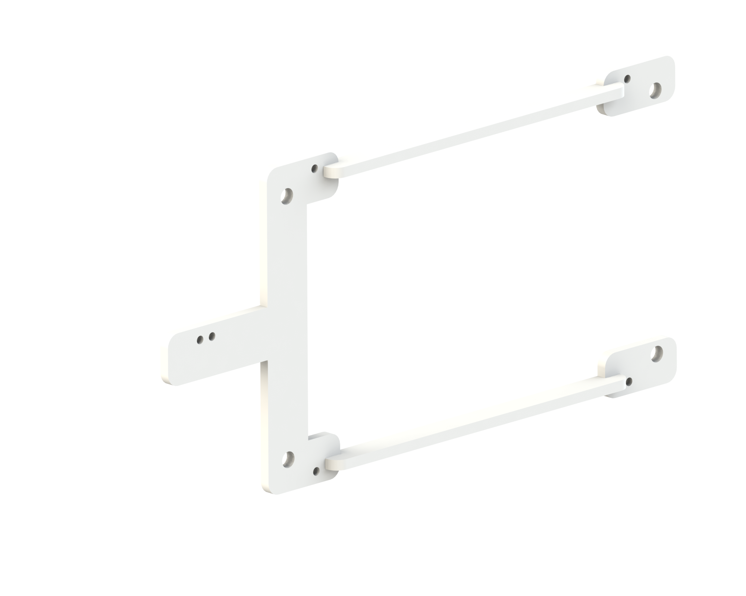
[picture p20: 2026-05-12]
General Project/V1 (EG3301R)/General - EG3301R - Box Bunny/Boxbunny Detailed Model/Renders/Final Report/Touchscreen Holder.png

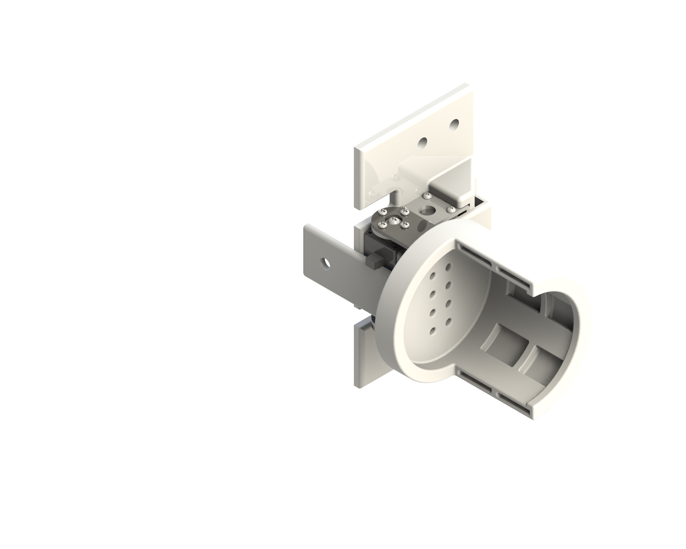
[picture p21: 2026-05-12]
General Project/V1 (EG3301R)/General - EG3301R - Box Bunny/Boxbunny Detailed Model/Renders/Final Report/Full Arm Holder.png

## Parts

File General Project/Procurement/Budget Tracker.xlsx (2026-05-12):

LPI # | Items Purchased | Total Cost
1 | 4x Damiao DM-J4310-2EC Motor (Including driver) + 1x USB to CAN debugging tool | $528.18
2 | 1x Worm Gear DHK2T Screw Jack + 0.37kW 3-phase AC Motor | $211.86
3 | 8080 Aluminium Extrusion: PTP-8080H-8 SLOT PROFILE 1x L=900MM 1x L=230MM | $99.41
4 | Steel Material & Welding: -SHS Tube 120x120mm inT10mm -Steel Plate 320x320mm inT10mm | $223.45
5 | UGREEN USB C Cable Type C Cable, USB A to USB C Lead, QC 3.0 Fast Charging Nylon Cord, Data Transfer [3m, straight] | $12.98
6 | Cursor Subscription Mthly [Pro+ -- 3x usage on all OpenAI, Claude, Gemini models] | $78.72
7 | Colab Pro Subscription Mthly | $14.46
8 | Colab Pro Additional 100 Compute Units | $14.46
9 | WEICON Rust Converter - 400ml | $24.40
10 | WEICON Zinc Spray - 400ml | $24.40
11 | Nippon Paint Pylox Spray Paint - 47 Matte BLACK | $10.60
12 | Small Pulley [HTD8M 20 teeth 32mm width 15mm inner hole] | $107.82
13 | Large Pulley [HTD8M 70 teeth 32mm width 16mm inner hole]
14 | Idler Pulley [HTD8M smooth surface 32mm width 10mm inner hole]
15 | Timing Belt: Rubber timing belt HTD8M936/944/952/960/968/976/984/992/1000/1008 [HTD8M952]
16 | Anti-slip self-adhesive tape [10.0 cm wide * 2 m long [Black]]
17 | 3D Printing Filament Rolls [PETG BLACK 1kg x6]
18 | Spring [14cm length] | $20.21
19 | ZEPHYR VINYL, BROWN, 137CM | $50.40
20 | Nail Gun Refill -- Max Refill 1208-FA | $6.16
21 | Wooden Plate - PINE Val Plaque 5x7 Oval Plaid x3 | $10.95
22 | Replacement Wheels for Casters (680g) [RMNA100] | $383.14
23 | SSFH-640SF-SUS (RIVET NUT FOR BASE_FEET) POP STANDARD NUT SSFHSF (32g) POP_RIVETS
24 | KCLSBF12-62 (PIN FOR REAR WHEELS) Pivot Pins - Diameter Tolerance Selectable (160g) MISUMI
25 | C-CFFRUCS10-22 (FOR ROLLER) Nylon Coated Cam Followers (224g) MISUMI
26 | CMFLB10-25 (FOR ROLLER) Brackets for Cam Followers-L-Shaped CAMFOLLOWER (4g) MISUMI
27 | Timing Belt: Rubber timing belt HTD8M936/944/952/960/968/976/984/992/1000/1008 [HTD8M968 x1, HTD8M984 x1] | $18.55
28 | Steel Material & Welding: - fab2_circular bottom: 15mm A6061- Machining ($72) - fab2_circular top: 10mm A6061- Machining ($245) - weld2_base feet: 3mm RHS75*50- Primer & Powder coat ($245) - weld2_base plate: 5mm MS- Primer & Powder coat ($110) | $732.48
29 | Raspberry Pi 10.1" HDMI Type-C Capacitive Touch LCD with Case 1280x800 | $130.20
30 | Sponge (FOR PADDING CUSHION): 高密度海绵垫子防震海绵块可裁剪海棉沙发靠背软包长条海绵坐垫片 High-density sponge cushions, shock-absorbing sponge blocks, cuttable sponge sofa backrest upholstery, long strip sponge [10cm thick, 50cm*50cm] | $42.11
31 | BASSWOOD PLYWOOD 22x15cm [x4] | $5.80
32 | AXIS Semi-SS Hose Clamps 32s 2 [x4] | $12.00
TOTAL SPENT |  | $2762.74
TOTAL BUDGET |  | $3200.00
TOTAL REMAINING |  | $437.26

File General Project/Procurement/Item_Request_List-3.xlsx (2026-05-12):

Project Code: |  | IS-431
Course Code: |  | CDE4301
Project Title: |  | BoxBunny
Main Project Supervisor: |  | Graham Zhu Hongjiao
Members
S/N | Name |  | Host Department | Matric No. | Email |  | Contact No. | Remarks
1 | Muhammad Zakir Haziq Bin Mohd Padzal |  | Engineering Science | A0257956J | e0968928@u.nus.edu |  | 96607351
2 | Muthukumaran Yogeeswaran |  | Engineering Science | A0253028L | yogeeswaran@u.nus.edu |  | 91774466
3 | Ng Jun Hao Elgin |  | Engineering Science | A0265721E | e1067157@u.nus.edu |  | 98199303
4 | Sim Yu Jeanette |  | Engineering Science | A0254736X | jeanette.sim@u.nus.edu |  | 80900677
S/N | Item Description & Part/Model No. |  | Class of Item ( Normal / Chemical / Biological / Hazardous*) | Unit price | Quantity | Sub Total | Distributor/Supplier/URL
1 | 8080 Aluminium Extrusions: PTP-8080H-8 SLOT PROFILE L=900MM PTP-8080H-8 SLOT PROFILE L=230MM |  | Normal | L = 900mm: $72.40 L = 230mm: $18.80 | 2 | $99.41 | Prestech Industrial Automation PTE LTD: https://prestech.com.sg/house-products/aluminium-profiles/80series/product/product/56-PTP-8080H-8
 |  |  |  |  | Grand Total | $99.41
* Important Note:
1. Please take note that the claim for reimbursement of any purchases must be submitted within 1 month. No claim is allowed after 1 month of purchase.
2. For Chemical / Biological / Hazardous item(s) - Please indicate the safe handling requirements through a risk assessment, and provide the Safety Data Sheet (SDS).
3. The safe handling requirements include the usage, PPE, transfer/transportation, storage and disposal of the item(s).
4. For Hazardous item - Government license (such as from NEA, SCDF, SPF or AVA) is required. Hence, there might be additional cost involved for the licensing fee.
5. The safety documents submitted will be reviewed by the Acting License Holder (ALH) or the Faculty Safety Manager.

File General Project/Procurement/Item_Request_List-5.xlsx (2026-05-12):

Project Code: |  | IS-431
Course Code: |  | CDE4301
Project Title: |  | BoxBunny
Main Project Supervisor: |  | Graham Zhu Hongjiao
Members
S/N | Name |  | Host Department | Matric No. | Email |  | Contact No. | Remarks
1 | Muhammad Zakir Haziq Bin Mohd Padzal |  | Engineering Science | A0257956J | e0968928@u.nus.edu |  | 96607351
2 | Muthukumaran Yogeeswaran |  | Engineering Science | A0253028L | yogeeswaran@u.nus.edu |  | 91774466
3 | Ng Jun Hao Elgin |  | Engineering Science | A0265721E | e1067157@u.nus.edu |  | 98199303
4 | Sim Yu Jeanette |  | Engineering Science | A0254736X | jeanette.sim@u.nus.edu |  | 80900677
S/N | Item Description & Part/Model No. |  | Class of Item ( Normal / Chemical / Biological / Hazardous*) | Unit price | Quantity | Sub Total | Distributor/Supplier/URL
1 | UGREEN USB C Cable Type C Cable, USB A to USB C Lead, QC 3.0 Fast Charging Nylon Cord, Data Transfer [3m, straight] |  | Normal | $10.99 | 1 | $12.98 | Shopee: https://shopee.sg/UGREEN-USB-C-Cable-Type-C-Cable-USB-A-to-USB-C-Lead-QC-3.0-Fast-Charging-Nylon-Cord-Data-Transfer-i.515574539.15371746166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
2 | Cursor Subscription Mthly (One-time) [Pro+ -- 3x usage on all OpenAI, Claude, Gemini models] |  | Normal | USD$60 | 1 | $80.92 | Cursor: https://cursor.com/pricing
3 | Colab Pro Subscription Mthly |  | Normal | $14.46 | 1 | $14.46 | Colab: https://colab.research.google.com/signup
4 | Colab Pro Additional 100 Compute Units |  | Normal | $14.46 | 1 | $14.46 | Colab: https://colab.research.google.com/signup
6 | WEICON Rust Converter 400 ml | Stops Corrosion | Corrosion protection | indoor & outdoor |  | Chemical | $25.73 | 1 | $24.40 | Shopee: https://shopee.sg/WEICON-Rust-Converter-400-ml-Stops-Corrosion-Corrosion-protection-indoor-outdoor-i.269081818.7653944654
7 | WEICON Zinc Spray 400 ml *TÜV-Tested* Quick-Drying, heat-resistant and suitable as primer for metal |  | Chemical | $24.78 | 1 | $24.40 | Shopee: https://shopee.sg/WEICON-Zinc-Spray-400-ml-*T%C3%9CV-Tested*-Quick-Drying-heat-resistant-and-suitable-as-primer-for-metal-i.269081818.3342198677
8 | Nippon Paint Pylox Spray Paint - 47 MATTE BLACK |  | Chemical | $8.90 | 1 | $10.60 | Shopee: https://shopee.sg/Nippon-Paint-Pylox-Spray-Paint-(Solid-Colours-01-66)-66-colours-available-i.266365323.20775938953
 |  |  |  |  | Grand Total | $182.22
* Important Note:
1. Please take note that the claim for reimbursement of any purchases must be submitted within 1 month. No claim is allowed after 1 month of purchase.
2. For Chemical / Biological / Hazardous item(s) - Please indicate the safe handling requirements through a risk assessment, and provide the Safety Data Sheet (SDS).
3. The safe handling requirements include the usage, PPE, transfer/transportation, storage and disposal of the item(s).
4. For Hazardous item - Government license (such as from NEA, SCDF, SPF or AVA) is required. Hence, there might be additional cost involved for the licensing fee.
5. The safety documents submitted will be reviewed by the Acting License Holder (ALH) or the Faculty Safety Manager.

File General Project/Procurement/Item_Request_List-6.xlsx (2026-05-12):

Project Code: |  | IS-431
Course Code: |  | CDE4301
Project Title: |  | BoxBunny
Main Project Supervisor: |  | Graham Zhu Hongjiao
Members
S/N | Name |  | Host Department | Matric No. | Email |  | Contact No. | Remarks
1 | Muhammad Zakir Haziq Bin Mohd Padzal |  | Engineering Science | A0257956J | e0968928@u.nus.edu |  | 96607351
2 | Muthukumaran Yogeeswaran |  | Engineering Science | A0253028L | yogeeswaran@u.nus.edu |  | 91774466
3 | Ng Jun Hao Elgin |  | Engineering Science | A0265721E | e1067157@u.nus.edu |  | 98199303
4 | Sim Yu Jeanette |  | Engineering Science | A0254736X | jeanette.sim@u.nus.edu |  | 80900677
S/N | Item Description & Part/Model No. |  | Class of Item ( Normal / Chemical / Biological / Hazardous*) | Unit price | Quantity | Sub Total | Distributor/Supplier/URL
1 | Replacement Wheels for Casters [RMNA100] |  | Normal | $7.58 | 2 | $15.16 | Misumi: https://sg.misumi-ec.com/vona2/detail/110300500620/?ProductCode=RMNA100
2 | Small Pulley: 45钢同步皮带轮8M20齿精加工两面平同步轮槽宽26/32/42无台带轮 45 steel synchronous belt pulley, 8M20 teeth, precision machined, double-sided flat, synchronous pulley groove width 26/32/42, no platform pulley. [金色 8M宽32孔15带键槽 Gold 8M wide 32 holes 15 with keyway] |  | Normal | ￥35.42 | 1 | $9.05 | Taobao: https://item.taobao.com/item.htm?from=cart&id=679314184275&skuId=5049636415667&upStreamPrice=2967 |  | $61.63
3 | Large Pulley: 8M70齿同步轮同步带轮皮带轮 标准件铝合金齿外径176.89 3D打印机 8M70 toothed synchronous pulley/pulley, standard aluminum alloy tooth outer diameter 176.89 mm, for 3D printers. [8M70齿 齿宽32 工艺孔≈16, 8M70 tooth width 32, process hole ≈16] |  | Normal | ￥172.50 | 1 | $37.64 | Taobao: https://item.taobao.com/item.htm?from=cart&id=680104087498&skuId=4876111797812&upStreamPrice=17250
4 | Idler Pulley: 8M25齿 槽宽26/32/42带轴承同步轮 涨紧轮调节轮外径62.9 8M25 toothed pulley with a tooth width of 26/32/42, bearing-equipped synchronous pulley, tensioner pulley, and adjusting pulley; outer diameter 62. [8M25（光面）齿宽32内孔10, 8M25 (smooth surface) tooth width 32, inner diameter 10] |  | Normal | ￥35.42 | 1 | $9.05 | Taobao: https://item.taobao.com/item.htm?from=cart&id=679258516887&upStreamPrice=3542&skuId=4876731941225
5 | Timing Belt: 同步带皮带HTDS3M5M8MXLXH橡胶双面齿轮齿形传动带聚氨酯钢丝开口 Synchronous belt HTDS3M5M8MXLXH rubber double-sided gear toothed transmission belt polyurethane steel wire open [同步轮配套定制 Synchronous pulley matching customization - 952mm] |  | Normal | ￥35.00 | 1 | $7.22 | Taobao: https://item.taobao.com/item.htm?from=cart&id=612362967048&upStreamPrice=1000
6 | 3D Printing Filament: 爆款】R3D PETG 3D打印耗材肤色透明1.75mm高韧性打印笔材料拓竹打印机器通用大理石耐高温结构模型 [Hot Item] R3D PETG 3D Printing Material, Skin-tone Transparent, 1.75mm High-Toughness Printing Pen Mater [PETG 黑色 1kg【经济款】 PETG Black 1kg [Economy Size]] |  | Normal | ￥25.73 | 6 | $33.47 | Taobao: https://detail.tmall.com/item.htm?from=cart&id=750164175683&upStreamPrice=2490&skuId=5340822562426 |  | $6.70
7 | Nail Gun Refill -- Max Refill 1208-FA |  | Normal | $6.16 | 1 | $6.16 | Art Friend |  | $39.49
8 | Wooden Plate - PINE Val Plaque 5x7 Oval Plaid |  | Normal | $3.65 | 3 | $10.95 | Art Friend |  | $20.21
9 | ZEPHYR VINYL, BROWN, 137CM |  | Normal | $50.40 | 1 | $50.40 | Spotlight |  | $6.16
10 | Anti-slip self-adhesive tape: 米乐奇防滑网格纹硅橡胶皮单面自粘耐磨密封硅胶条背胶网格纹橡胶垫 [10.0 cm wide * 2 m long [Black]] |  | Normal | ￥31.60 | 1 | $10.34 | Taobao: https://detail.tmall.com/item.htm?from=cart&id=831478073528&upStreamPrice=3160 |  | $10.95
11 | 304 stainless steel spring with low pressure, custom shock absorption, high pressure return steel wire compression tension spring [Free length: 140mm Outer diameter (OD):35mm Wire diameter:4 mm Spring rate:10 N/mm Material:Music wire (ASTM A228) Type: Compression, closed and ground ends] |  | Normal | ￥8 | 1 | $5.42 | Taobao: https://detail.tmall.com/item.htm?from=cart&id=601646165812&skuId=4913884128283&upStreamPrice=800 |  | $50.40
 |  |  |  |  | Grand Total | $194.86 |  |  | $195.54
* Important Note:
1. Please take note that the claim for reimbursement of any purchases must be submitted within 1 month. No claim is allowed after 1 month of purchase.
2. For Chemical / Biological / Hazardous item(s) - Please indicate the safe handling requirements through a risk assessment, and provide the Safety Data Sheet (SDS).
3. The safe handling requirements include the usage, PPE, transfer/transportation, storage and disposal of the item(s).
4. For Hazardous item - Government license (such as from NEA, SCDF, SPF or AVA) is required. Hence, there might be additional cost involved for the licensing fee.
5. The safety documents submitted will be reviewed by the Acting License Holder (ALH) or the Faculty Safety Manager.

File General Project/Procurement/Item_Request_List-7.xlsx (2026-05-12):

Project Code: |  | IS-431
Course Code: |  | CDE4301
Project Title: |  | BoxBunny
Main Project Supervisor: |  | Graham Zhu Hongjiao
Members
S/N | Name |  | Host Department | Matric No. | Email |  | Contact No. | Remarks
1 | Muhammad Zakir Haziq Bin Mohd Padzal |  | Engineering Science | A0257956J | e0968928@u.nus.edu |  | 96607351
2 | Muthukumaran Yogeeswaran |  | Engineering Science | A0253028L | yogeeswaran@u.nus.edu |  | 91774466
3 | Ng Jun Hao Elgin |  | Engineering Science | A0265721E | e1067157@u.nus.edu |  | 98199303
4 | Sim Yu Jeanette |  | Engineering Science | A0254736X | jeanette.sim@u.nus.edu |  | 80900677
S/N | Item Description & Part/Model No. |  | Class of Item ( Normal / Chemical / Biological / Hazardous*) | Unit price | Quantity | Sub Total | Distributor/Supplier/URL |  | $18.55
1 | Replacement Wheels for Casters (680g) [RMNA100] |  | Normal | $7.58 | 2 | $15.16 | Misumi: https://sg.misumi-ec.com/vona2/detail/110300500620/?ProductCode=RMNA100 |  | $130.20
2 | SSFH-640SF-SUS (RIVET NUT FOR BASE_FEET) POP STANDARD NUT SSFHSF (32g) POP_RIVETS |  | Normal | $3.72 | 8 | $29.76 | Misumi: https://sg.misumi-ec.com/vona2/detail/221000765913/?HissuCode=SSFH-640SF-SUS |  | $42.11
3 | KCLSBF12-62 (PIN FOR REAR WHEELS) Pivot Pins - Diameter Tolerance Selectable (160g) MISUMI |  | Normal | $18.61 | 2 | $37.22 | Misumi: https://sg.misumi-ec.com/vona2/detail/110300098460/?HissuCode=KCLSBF12-62 |  | $732.48
4 | C-CFFRUCS10-22 (FOR ROLLER) Nylon Coated Cam Followers (224g) MISUMI |  | Normal | $24.89 | 4 | $99.56 | Misumi: https://sg.misumi-ec.com/vona2/detail/110310339929/?HissuCode=C-CFFRUCS10-22 |  | $5.80
5 | CMFLB10-25 (FOR ROLLER) Brackets for Cam Followers-L-Shaped CAMFOLLOWER (4g) MISUMI |  | Normal | $42.45 | 4 | $169.80 | Misumi: https://sg.misumi-ec.com/vona2/detail/110300500620/?ProductCode=RMNA104 |  | $342.57
6 | Timing Belt: Rubber timing belt HTD8M936/944/952/960/968/976/984/992/1000/1008 [HTD8M968 x1, HTD8M984 x1] |  | Normal | ￥11.40 | 2 | $18.55 | Taobao: https://item.taobao.com/item.htm?id=665404763675&sku_properties=1627207%3A796156728 |  | $40.57
7 | Steel Material & Welding: - fab2_circular bottom: 15mm A6061- Machining ($72) - fab2_circular top: 10mm A6061- Machining ($245) - weld2_base feet: 3mm RHS75*50- Primer & Powder coat ($245) - weld2_base plate: 5mm MS- Primer & Powder coat ($110) |  | Normal | $672.00 | 1 | $672.00 | MIKYO TECH METAL FABRICATION (S) PTE. LTD. |  | $12.00
8 | Raspberry Pi 10.1" HDMI Type-C Capacitive Touch LCD with Case 1280x800 |  | Normal | $130.20 | 1 | $130.20 | Kuriosity |  | $1324.28
9 | Sponge (FOR PADDING CUSHION) 高密度海绵垫子防震海绵块可裁剪海棉沙发靠背软包长条海绵坐垫片 High-density sponge cushions, shock-absorbing sponge blocks, cuttable sponge sofa backrest upholstery, long strip sponge [10cm thick, 50cm*50cm] |  | Normal | $4.28 | 4 | $17.12 | Taobao: https://item.taobao.com/item.htm?app=chrome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
 |  |  |  |  | Grand Total | $1189.37
* Important Note:
1. Please take note that the claim for reimbursement of any purchases must be submitted within 1 month. No claim is allowed after 1 month of purchase.
2. For Chemical / Biological / Hazardous item(s) - Please indicate the safe handling requirements through a risk assessment, and provide the Safety Data Sheet (SDS).
3. The safe handling requirements include the usage, PPE, transfer/transportation, storage and disposal of the item(s).
4. For Hazardous item - Government license (such as from NEA, SCDF, SPF or AVA) is required. Hence, there might be additional cost involved for the licensing fee.
5. The safety documents submitted will be reviewed by the Acting License Holder (ALH) or the Faculty Safety Manager.

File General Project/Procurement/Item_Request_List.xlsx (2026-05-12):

Project Code: |  | IS-431
Course Code: |  | CDE4301
Project Title: |  | BoxBunny
Main Project Supervisor: |  | Graham Zhu Hongjiao
Members
S/N | Name |  | Host Department | Matric No. | Email |  | Contact No. | Remarks
1 | Muhammad Zakir Haziq Bin Mohd Padzal |  | Engineering Science | A0257956J | e0968928@u.nus.edu |  | 96607351
2 | Muthukumaran Yogeeswaran |  | Engineering Science | A0253028L | yogeeswaran@u.nus.edu |  | 91774466
3 | Ng Jun Hao Elgin |  | Engineering Science | A0265721E | e1067157@u.nus.edu |  | 98199303
4 | Sim Yu Jeanette |  | Engineering Science | A0254736X | jeanette.sim@u.nus.edu |  | 80900677
S/N | Item Description & Part/Model No. |  | Class of Item ( Normal / Chemical / Biological / Hazardous*) | Unit price | Quantity | Sub Total | Distributor/Supplier/URL
1 | Super Lube Multi-purpose Synthetic Grease 85g, Food Grade Grease for SAECO PHILIPS Coffee Machine |  | Normal | $13.28 | 1 | $15.27 | https://shopee.sg/product/619444006/26514442161?d_id=1e8b0&uls_trackid=54k3fslu00ls
2 | 3D Printing Filament Tpu 85A&90A Flexible Soft Elastic Shock-Absorbing 3D Filament for Bambu Lab |  | Normal | $42.53 | 2 | $85.06 | https://click.world.taobao.com/_b.bbF9xl
4 | Teensy 4.1 Controller Board |  | Normal | $56.79 | 1 | $56.79 | https://sg.cytron.io/p-teensy-4p1-controller-board
5 | Screw Lift, Screw Lift Platform, Swl Hand-Cranked Manual Electric Lift, Worm Gear, Worm Screw, Small Micro Spiral |  | Normal | $51.57 | 1 | $51.57 | https://click.world.taobao.com/_b.XbFgfe
6 | 4x Damiao DM-J4310-2EC Motor (Including driver) + 1x USB to CAN debugging tool |  | Normal | $545.33 | 1 | $545.33 | https://click.world.taobao.com/_b.ibkd8a
7 | Intel intel realsense real sense camera d415/d435/d455 binocular depth sensing camera [D435i bulk work package] |  | Normal | $524.19 | 1 | $524.19 | https://item.taobao.com/item.htm?from=cart&id=622419189453&skuId=5858009069665&upStreamPrice=250000
 |  |  |  |  | Grand Total | $1278.21
* Important Note:
1. Please take note that the claim for reimbursement of any purchases must be submitted within 1 month. No claim is allowed after 1 month of purchase.
2. For Chemical / Biological / Hazardous item(s) - Please indicate the safe handling requirements through a risk assessment, and provide the Safety Data Sheet (SDS).
3. The safe handling requirements include the usage, PPE, transfer/transportation, storage and disposal of the item(s).
4. For Hazardous item - Government license (such as from NEA, SCDF, SPF or AVA) is required. Hence, there might be additional cost involved for the licensing fee.
5. The safety documents submitted will be reviewed by the Acting License Holder (ALH) or the Faculty Safety Manager.

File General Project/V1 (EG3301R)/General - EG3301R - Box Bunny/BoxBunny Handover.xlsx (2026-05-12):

Item No | Item Name | Quantity | Purchase/Loan | Location
1 | 60kg 127mm Mecanum wheels | 4 | Purchase | On prototype
2 | 35kg 180 degree servo motor | 4 | Purchase | On prototype
3 | 5VDC HC-SR04 Ultrasonic Sensor | 6 | Purchase | On prototype
4 | 10A 7V-35V DC Motor Driver | 2 | Purchase | On prototype
5 | 24V 10Ah 7S4P Lithium Ion Battery | 1 | Purchase | On prototype
6 | 5A DC-DC Buck Converter | 2 | Purchase | On prototype
7 | Raspberry Pi 5 | 1 | Purchase | On prototype
8 | 7inch HDMI LCD | 1 | Purchase | On prototype
9 | Pixy2 Camera | 1 | Purchase | On prototype
10 | Arduino Mega | 1 | Purchase | On prototype
11 | Arduino Uno | 1 | Purchase | On prototype
12 | KS2 Spring & Rubber Caps | 1 | Purchase | On prototype
13 | 32GB SD Card | 1 | Purchase | On prototype
14 | 50cm Official Raspberry Pi 5 CSI Cable for Camera | 1 | Purchase | On prototype
15 | Cable, Type A Plug to Type B Plug, 2 m, USB 2.0 | 1 | Purchase | On prototype

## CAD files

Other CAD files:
CAD Model/Final/Bottom Assembly/v4_Fair/Final Fab/Single Exterior Alu Bracket/HBLTF8-C-SEP.sldasm
CAD Model/Final/Bottom Assembly/v4_Fair/v3_fair_assem_Upper/head assembly.SLDASM
CAD Model/Final/Bottom Assembly/v6_send/v6_assem base.SLDASM
CAD Model/Final/Bottom Assembly/v7/slewing bearing/010-10-120 bearing-jntes.SLDASM
CAD Model/Final/Bottom Assembly/v7/v7_assem base-jntes.SLDASM
CAD Model/Final/Bottom Assembly/v7_fab/circular plate/assem_circular plate.SLDASM
CAD Model/Final/Bottom Assembly/v7_fab/slewing bearing/010-10-120 bearing.SLDASM
CAD Model/Final/Bottom Assembly/v7_fab/v7_fab_assem base.SLDASM
CAD Model/Final/FINAL ASSEM/BOTTOM ASSEM FINAL/assem platform jack.SLDASM
CAD Model/Final/FINAL ASSEM/ELECTRONIC HOUSING ASSEM/power-supply-lrs-150-1.snapshot.3/24V Power Supply-LRS-150.SLDASM
CAD Model/Final/FINAL ASSEM/FINAL ASSEM.SLDASM
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

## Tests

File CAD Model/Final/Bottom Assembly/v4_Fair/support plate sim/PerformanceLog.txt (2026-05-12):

Number of Contacts: 9
Number of contact data: 11414

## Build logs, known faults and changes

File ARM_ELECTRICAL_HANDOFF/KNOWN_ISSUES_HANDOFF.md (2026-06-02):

# BoxBunny Project: Known Issues & Troubleshooting Handoff

## Overview

This document serves as a technical handoff for the next development phase of the BoxBunny project, specifically focusing on the Upper Mechanism, Padding, and Height Adjustment subsystems. It outlines active limitations, mitigated risks requiring hardware upgrades, and a historical log of resolved defects to prevent regression.

---

## 1. Active Known Issues & Mitigations (Action Required)

### 1.1 ODrive Regen Clamp: Threshold Calibration & Resistor Validation
- **Layer:** Electrical (Power)
- **Status:** ⚠️ Active Issue (Calibration Fixed; Dynamic Sizing Pending)
- **Historical Symptom:** The ODrive power resistor was actively heating up and smoking even when the motors were completely stationary.
- **Diagnosed Root Cause (Resolved):** The clamping threshold potentiometer on the Regen Clamp V0.3 was uncalibrated and set below the nominal 24V bus voltage. This caused a continuous "tug-of-war" where the clamp was permanently open, actively dumping the main power supply's continuous current directly into the brake resistor, treating it as a dead short.
- **Handoff Action (Calibration Rule):** The threshold has been corrected. For all future tuning, the Regen Clamp must be calibrated under power but completely idle. The potentiometer must be turned until the blue indicator light turns off, ensuring the threshold (e.g., 26.5V) sits safely above the power supply's nominal output.
- **Handoff Action (Dynamic Hardware Sizing):** While the continuous smoking issue was resolved via calibration, the current test resistors (10W/25W) are still mathematically undersized for the kinetic energy of a dynamic sparring load. The next team must calculate the peak regenerative Joules for both the Base Rotation and Height Adjustment axes. Heavy-duty Aluminium Wirewound Resistors (e.g., 100W+) must be sourced and bolted to the metal chassis for thermal mass before full-speed kinematic testing resumes.
### 1.2 I²C Blocking Trap & CAN Bus Starvation

- **Layer:** Firmware (I²C / CAN interaction) & GUI
- **Status:** ⚠️ Active Issue (Firmware Flash & GUI Updates Pending)
- **Symptom:** When an MPU6050 sensor fails or disconnects, the Teensy freezes while waiting for an I²C timeout. This starves the Damiao motors of their 200Hz trajectory updates, causing violent motor stuttering and feeding zeroed "garbage" sensor data into the upstream control logic.
- **Root Cause:** The default Arduino `Wire` library uses blocking calls (`requestFrom`), meaning IMU polling failure directly blocks CAN transmission.
- **Current Mitigation:** A new **Teensy Firmware V5** (`teensy_firmware_V5.ino`) has been written. It implements a 3ms hardware I²C timeout (`Wire.setWireTimeout(3000, true)`) and a global `imu_healthy` flag to safely drop the robot into a limp mode on sensor failure.
- **Handoff Action:** Future teams **must flash the Teensy with Firmware V5**. Additionally, the **GUI must be updated and calibrated** to properly support this change (e.g., catching the limp state flag if `imu_healthy` fails, and showing a user-facing alert instead of continuing to send commands).

### 1.3 Structural Failures on 3D Printed Gears

- **Layer:** Mechanical Design
- **Status:** ⚠️ Active Issue (Hardware Upgrades Pending)
- **Symptom:** The current 3D printed gears are experiencing structural failures under operational loads.
- **Handoff Action:**
  1. **Short-Term Mitigation:** Reinforce the existing 3D printed gears with metal shafts to better distribute shear stress.
  2. **Long-Term Resolution:** Move towards fully metal gears with proper machined parts for durable, long-term reliability.

---

## 2. Resolved Defects (Regression Watchlist)

These defects were successfully resolved but are documented here to prevent future teams from inadvertently reverting the fixes during refactoring.

### 2.1 I²C Bus Hang on Long-Wire IMU Routing (Padding)

- **Layer:** Firmware (Electrical → Software boundary)
- **Root Cause:** Long unshielded jumper wires (30–40 cm) to the padding IMUs introduced parasitic capacitance. At 400 kHz Fast Mode, the I²C "Repeated Start" condition failed, causing the MPU6050 to latch the SDA line low and freeze the entire bus.
- **Resolution:** Implemented a **Hard STOP protocol** (`endTransmission(true)`) after every register write. This forces a full STOP + START sequence, resetting the MPU6050 state machine reliably. This adds ~20 µs of latency per read but guarantees bus stability.

### 2.2 Nyquist Blind-Spot in Strike Detection (Padding)

- **Layer:** Application (GUI software)
- **Root Cause:** The GUI refreshed at 20 Hz, but a punch impulse lasts ~30 ms. The original logic only checked the _latest_ sample at each GUI tick, completely missing inter-frame strikes (Nyquist blind-spot).
- **Resolution:** Upgraded to **Scan-window peak detection** (`np.max(mag_arr[-n_scan:])`), which evaluates all buffered samples (~10 samples at 200 Hz firmware rate) since the last GUI tick.

### 2.3 Motor Jitter & Boomerang Effect (Arm Actuation)

- **Layer:** Middleware (ROS 2) & Firmware
- **Root Cause:** Publishing CAN commands at the full 50 Hz ROS callback rate continuously reset the Damiao motor's internal trajectory planner, preventing smooth motion. Additionally, ghost GUI nodes published conflicting zero-targets.
- **Resolution:**
  1. Implemented **Sparse Edge-Triggering**: CAN commands are only published on position changes >0.01 rad or every 100 ms as a keep-alive.
  2. Pre-launch cleanup routine (`killall -9 python3`) added to kill ghost ROS nodes.

### 2.4 Micro-ROS Agent Disconnect Hang (Firmware)

- **Layer:** Firmware (micro-ROS transport)
- **Root Cause:** WSL USB passthrough drivers failed to signal DTR/RTS teardown when the host port closed, leaving the Teensy permanently hung in an `AGENT_CONNECTED` state.
- **Resolution:** Implemented a 1 Hz active ping. After 3 failed pings (1.5 s), the firmware triggers a **hardware silicon reset** (`SCB_AIRCR = 0x05FA0004`) for a clean reconnection state.

### 2.5 Phantom 8–9A Idle Current (Firmware)

- **Layer:** Firmware (CAN parsing)
- **Root Cause:** The Damiao motor encodes torque as a 12-bit integer, but the firmware parsed it as a 16-bit float, absorbing the adjacent temperature byte and causing wild current readings.
- **Resolution:** Corrected the CAN unpacking logic to cleanly extract the 12-bit MIT Torque field.

### 2.6 MDDS10 PWM/DIR Pin Transposition (Firmware)

- **Layer:** Firmware + Documentation
- **Root Cause:** Original wiring documentation transposed the AN1 (speed) and DIG1 (direction) labels, causing the motor to run at constant full speed while ignoring commands.
- **Resolution:** Swapped pins in firmware; wiring documentation has been corrected.

---

## 3. Important Architectural Quirks

### 3.1 Joint-Space Pitch Clamping

Because of the coaxial differential coupling, simple per-motor position clamping is impossible. Any roll rotation physically drives the pitch mechanism. To prevent the arm from breaking its structural limits during compound movements, limits are enforced via a **joint-space clamping pass** in `homing_tab.py`. Motor targets are converted to joint space, pitch is clamped, and then converted back to motor commands. **Do not attempt to implement basic motor-space clamping.**

### 3.2 Tactical Walking

The bevel gear "walking" effect (where Motor 1 and Motor 2 rotating in opposition produces a rearing motion) is an **intentional choreographic asset**. It is used purposefully in strike patterns like the "Jab Windup" to clear the user's defensive perimeter. It should be treated as a feature of the 4-quadrant actuation space, not a bug.

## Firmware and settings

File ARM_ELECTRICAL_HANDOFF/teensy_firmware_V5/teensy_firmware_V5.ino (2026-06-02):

#include <micro_ros_arduino.h>
#include <stdio.h>
#include <string.h>
#include <math.h>
#include <Wire.h>

// --- COMPATIBILITY PATCH ---
#include <ctype.h>
#undef __locale_ctype_ptr
extern "C" {
  const unsigned char * __locale_ctype_ptr (void) { return (const unsigned char *)_ctype_; }
}
// ---------------------------

#define NONE RCLC_NONE_PLACEHOLDER
#include <rcl/rcl.h>
#include <rcl/error_handling.h>
#include <rclc/rclc.h>
#include <rclc/executor.h>
#undef NONE

#include <std_msgs/msg/float64_multi_array.h>
#include <std_msgs/msg/string.h>
#include <FlexCAN_T4.h>

// =============================================================================
// FIRMWARE V4 — Motor Control + IMU Integration (200Hz Unified Loop)
// =============================================================================
// Extends V3 with:
//   - I2C polling of up to 4 MPU6050 IMUs (Wire + Wire1, 0x68 + 0x69)
//   - Extended feedback payload: 21 doubles (motor pos/curr + IMU accel)
//   - 200Hz unified control + feedback loop (5ms intervals)
// =============================================================================


// --- HARDWARE CONFIG ---
FlexCAN_T4<CAN1, RX_SIZE_256, TX_SIZE_16> Can0;

const int ID_LEFT_1  = 0x01;
const int ID_LEFT_2  = 0x02;
const int ID_RIGHT_1 = 0x03;
const int ID_RIGHT_2 = 0x04;

// --- IMU CONFIG ---
const int MPU_ADDR_1 = 0x68;
const int MPU_ADDR_2 = 0x69;
bool imu1_active = false;   // Wire,  0x68
bool imu2_active = false;   // Wire,  0x69
bool imu3_active = false;   // Wire1, 0x68
bool imu4_active = false;   // Wire1, 0x69

// IMU acceleration data (m/s²), updated each loop
float imu_accel[4][3] = {{0}};   // [imu_index][axis: x,y,z]

// --- DYNAMIC MECHANICAL LIMITS (Kinematic Decoupling) ---
void apply_dynamic_endstops(float targets[4]) {
    const float GLOBAL_SAFE_MAX = 50.0;
    const float GLOBAL_SAFE_MIN = -50.0;
    for (int i = 0; i < 4; i++) {
        if (targets[i] > GLOBAL_SAFE_MAX) targets[i] = GLOBAL_SAFE_MAX;
        if (targets[i] < GLOBAL_SAFE_MIN) targets[i] = GLOBAL_SAFE_MIN;
    }
}

// --- DATA GLOBALS ---
float target_pos[4] = {0.0};
float target_speed[4] = {5.0, 5.0, 5.0, 5.0};
float actual_pos[4] = {0.0};
float actual_current[4] = {0.0};
float last_sent_pos[4] = {-9999.0, -9999.0, -9999.0, -9999.0};

bool motors_enabled = false;
uint32_t can_rx_count = 0;


// --- IMU FUNCTIONS ---
bool initMPU(TwoWire &wire, int addr) {
    wire.beginTransmission(addr);
    if (wire.endTransmission() != 0) return false;

    wire.beginTransmission(addr);
    wire.write(0x6B);  // PWR_MGMT_1
    wire.write(0);     // Wake up
    wire.endTransmission(true);

    wire.beginTransmission(addr);
    wire.write(0x1B);  // GYRO_CONFIG
    wire.write(0x00);  // ±250 dps
    wire.endTransmission(true);

    wire.beginTransmission(addr);
    wire.write(0x1C);  // ACCEL_CONFIG
    wire.write(0x18);  // ±16g (FS_SEL = 11) — full range for boxing impact detection
    wire.endTransmission(true);

    return true;
}

// Track consecutive errors per IMU slot to trigger auto-recovery
uint16_t imu_err_count[4] = {0, 0, 0, 0};
bool imu_healthy = true;

void readMPU(TwoWire &wire, int addr, int16_t* data, int slot_idx) {
    // If an IMU has been offline/failing heavily, attempt to re-awaken it every 50 loops (250ms)
    if (imu_err_count[slot_idx] > 10) {
        if (imu_err_count[slot_idx] % 50 == 0) {
            initMPU(wire, addr); // Send wake-up and config registers again
        }
    }

    wire.beginTransmission(addr);
    wire.write(0x3B);
    
    // Force a true STOP condition.
    if (wire.endTransmission(true) != 0) {
        for(int i=0; i<6; i++) data[i] = 0;
        imu_err_count[slot_idx]++;
        return;
    }
    
    // Validate that all 14 bytes successfully arrived.
    if (wire.requestFrom((uint8_t)addr, (size_t)14, true) == 14) {
        data[0] = wire.read() << 8 | wire.read();  // Accel X
        data[1] = wire.read() << 8 | wire.read();  // Accel Y
        data[2] = wire.read() << 8 | wire.read();  // Accel Z
        wire.read() << 8 | wire.read();             // Temperature (discard)
        data[3] = wire.read() << 8 | wire.read();  // Gyro X
        data[4] = wire.read() << 8 | wire.read();  // Gyro Y
        data[5] = wire.read() << 8 | wire.read();  // Gyro Z
        imu_err_count[slot_idx] = 0; // Success, reset error counter
    } else {
        for(int i=0; i<6; i++) data[i] = 0;
        while(wire.available()) wire.read(); // Drain bus
        imu_err_count[slot_idx]++;
    }
}

void readAllIMUs() {
    int16_t d1[6], d2[6], d3[6], d4[6];
    
    // Poll all 4 slots regardless of initial boot state (supports hot-plugging)
    readMPU(Wire,  MPU_ADDR_1, d1, 0);
    readMPU(Wire,  MPU_ADDR_2, d2, 1);
    readMPU(Wire1, MPU_ADDR_1, d3, 2);
    readMPU(Wire1, MPU_ADDR_2, d4, 3);

    // Convert raw int16 to m/s² (±16g range: 2048 LSB/g)
    int16_t* all[4] = {d1, d2, d3, d4};
    for (int i = 0; i < 4; i++) {
        for (int j = 0; j < 3; j++) {
            imu_accel[i][j] = ((float)all[i][j] / 2048.0f) * 9.81f;
        }
    }

    // Evaluate Global IMU Health
    imu_healthy = true;
    for (int i = 0; i < 4; i++) {
        // If an IMU fails to respond more than 3 consecutive times, mark system as unhealthy
        if (imu_err_count[i] > 3) {
            imu_healthy = false;
        }
    }
}


// --- ROS GLOBALS ---
rcl_subscription_t subscriber;
std_msgs__msg__Float64MultiArray msg_sub;
rcl_publisher_t feedback_pub;
std_msgs__msg__Float64MultiArray msg_feedback;


rclc_executor_t executor;
rclc_support_t support;
rcl_allocator_t allocator;
rcl_node_t node;

static double msg_data_buffer[9];
static double feedback_data_buffer[21];   // Extended: 9 motor + 12 IMU

#define LED_PIN 13

enum states { WAITING_AGENT, AGENT_AVAILABLE, AGENT_CONNECTED, AGENT_DISCONNECTED } state;

#define RCCHECK(fn) { rcl_ret_t temp_rc = fn; if((temp_rc != RCL_RET_OK)){ return false; }}
#define RCSOFTCHECK(fn) { rcl_ret_t temp_rc = fn; (void)temp_rc; }

float uint_to_float(int x_int, float x_min, float x_max, int bits) {
    float span = x_max - x_min;
    float offset = x_min;
    return ((float)x_int) * span / ((float)((1 << bits) - 1)) + offset;
}

void set_motor_state(uint16_t id, bool enable) {
    CAN_message_t msg;
    msg.id = id;
    msg.len = 8;
    for(int i=0; i<7; i++) msg.buf[i] = 0xFF;
    msg.buf[7] = enable ? 0xFC : 0xFD;
    Can0.write(msg);
}

void pack_and_send_pos_speed(uint8_t id, float p_des, float v_des) {
    CAN_message_t msg;
    msg.id = 0x100 + id;
    msg.len = 8;
    memcpy(&msg.buf[0], &p_des, 4);
    memcpy(&msg.buf[4], &v_des, 4);
    Can0.write(msg);
}

void read_can_feedback() {
    CAN_message_t msg;
    while(Can0.read(msg)) {
        can_rx_count++;

        int id_payload = msg.buf[0] & 0x0F;

        uint16_t p_int = ((uint16_t)msg.buf[1] << 8) | (uint16_t)msg.buf[2];
        float p = uint_to_float(p_int, -12.5663706f, 12.5663706f, 16);

        uint16_t t_int = (((uint16_t)(msg.buf[4] & 0x0F)) << 8) | (uint16_t)msg.buf[5];
        float t = uint_to_float(t_int, -10.0f, 10.0f, 12);

        int idx = -1;
        if (msg.id == ID_LEFT_1 || id_payload == ID_LEFT_1) idx = 0;
        else if (msg.id == ID_LEFT_2 || id_payload == ID_LEFT_2) idx = 1;
        else if (msg.id == ID_RIGHT_1 || id_payload == ID_RIGHT_1) idx = 2;
        else if (msg.id == ID_RIGHT_2 || id_payload == ID_RIGHT_2) idx = 3;

        if (idx != -1) {
            actual_pos[idx] = p;
            actual_current[idx] = t;
        }
    }
}

void subscription_callback(const void * msin) {
  const std_msgs__msg__Float64MultiArray * msg = (const std_msgs__msg__Float64MultiArray *)msin;

  if (msg->data.size >= 4) {
    for(int i=0; i<4; i++) {
        target_pos[i] = (float)msg->data.data[i];
    }
    apply_dynamic_endstops(target_pos);
  }
  if (msg->data.size >= 8) {
    for(int i=0; i<4; i++) target_speed[i] = (float)msg->data.data[4+i];
  }
  if (msg->data.size >= 9) {
    bool enable = (msg->data.data[8] > 0.5);
    if (enable != motors_enabled) {
        motors_enabled = enable;
        if(motors_enabled) {
             for(int i=0; i<4; i++) target_pos[i] = actual_pos[i];
             for(int i=0; i<5; i++) {
                set_motor_state(ID_LEFT_1, true); set_motor_state(ID_LEFT_2, true);
                set_motor_state(ID_RIGHT_1, true); set_motor_state(ID_RIGHT_2, true);
                delay(2);
             }
        } else {
             set_motor_state(ID_LEFT_1, false); set_motor_state(ID_LEFT_2, false);
             set_motor_state(ID_RIGHT_1, false); set_motor_state(ID_RIGHT_2, false);
        }
    }
  }
}

bool create_entities() {
  allocator = rcl_get_default_allocator();
  RCCHECK(rclc_support_init(&support, 0, NULL, &allocator));
  RCCHECK(rclc_node_init_default(&node, "dual_arm_bridge", "", &support));

  std_msgs__msg__Float64MultiArray__init(&msg_sub);
  msg_sub.data.capacity = 9; msg_sub.data.data = msg_data_buffer; msg_sub.data.size = 0;

  RCCHECK(rclc_subscription_init_default(&subscriber, &node,
    ROSIDL_GET_MSG_TYPE_SUPPORT(std_msgs, msg, Float64MultiArray), "motor_commands"));

  std_msgs__msg__Float64MultiArray__init(&msg_feedback);
  msg_feedback.data.capacity = 21;
  msg_feedback.data.data = feedback_data_buffer;
  msg_feedback.data.size = 0;

  RCCHECK(rclc_publisher_init_default(&feedback_pub, &node,
    ROSIDL_GET_MSG_TYPE_SUPPORT(std_msgs, msg, Float64MultiArray), "motor_feedback"));



  RCCHECK(rclc_executor_init(&executor, &support.context, 2, &allocator));
  RCCHECK(rclc_executor_add_subscription(&executor, &subscriber, &msg_sub, &subscription_callback, ON_NEW_DATA));

  return true;
}

void destroy_entities() {
  RCSOFTCHECK(rcl_subscription_fini(&subscriber, &node));

  RCSOFTCHECK(rcl_publisher_fini(&feedback_pub, &node));
  RCSOFTCHECK(rclc_executor_fini(&executor));
  RCSOFTCHECK(rcl_node_fini(&node));
  RCSOFTCHECK(rclc_support_fini(&support));
}

void setup() {
  pinMode(LED_PIN, OUTPUT);

  // CAN Bus
  Can0.begin(); Can0.setBaudRate(1000000); Can0.setMBFilter(ACCEPT_ALL);

  // I2C Buses for IMUs (400kHz Fast Mode)
  Wire.begin();
  Wire.setClock(400000);
  Wire.setWireTimeout(3000, true); // 3ms timeout, reset on timeout
  Wire1.begin();
  Wire1.setClock(400000);
  Wire1.setWireTimeout(3000, true); // 3ms timeout, reset on timeout

  // Probe and initialize all IMU slots
  imu1_active = initMPU(Wire,  MPU_ADDR_1);
  imu2_active = initMPU(Wire,  MPU_ADDR_2);
  imu3_active = initMPU(Wire1, MPU_ADDR_1);
  imu4_active = initMPU(Wire1, MPU_ADDR_2);

  // micro-ROS transport
  Serial.begin(115200);
  set_microros_transports();
  state = WAITING_AGENT;
}

unsigned long last_ping = 0;
unsigned long last_feedback = 0;

void loop() {
  read_can_feedback();

  switch (state) {
    case WAITING_AGENT:
      if (millis() - last_ping > 100) {
          last_ping = millis();
          if (rmw_uros_ping_agent(100, 1) == RMW_RET_OK) state = AGENT_AVAILABLE;
          digitalWrite(LED_PIN, !digitalRead(LED_PIN));
      }
      break;
    case AGENT_AVAILABLE:
      state = create_entities() ? AGENT_CONNECTED : WAITING_AGENT;
      if (state == AGENT_CONNECTED) digitalWrite(LED_PIN, HIGH);
      break;
    case AGENT_CONNECTED:
      // Spin quickly, do not block the 200Hz loop
      if (rclc_executor_spin_some(&executor, RCL_MS_TO_NS(1)) != RCL_RET_OK) {
         SCB_AIRCR = 0x05FA0004;  // Hard Robot CPU Reboot
      }

      // Periodically verify agent is still alive so we don't hang if it's restarted via Ctrl+C
      static unsigned long last_agent_check = 0;
      static int missed_pings = 0;
      
      if (millis() - last_agent_check >= 500) {
          last_agent_check = millis();
          // Relaxed ping (10ms timeout)
          if (rmw_uros_ping_agent(10, 1) != RMW_RET_OK) {
              missed_pings++;
              if (missed_pings >= 3) {
                  // Hard reboot the Teensy 4.0 (ARM Cortex-M7) to cleanly obliterate the micro-ROS session
                  SCB_AIRCR = 0x05FA0004; 
              }
          } else {
              missed_pings = 0;
          }
      }

      // === Unified 200Hz Control + Feedback Loop (5ms interval) ===
      static unsigned long last_ctrl = 0;
      if (millis() - last_ctrl >= 5) {
         last_ctrl = millis();

         // --- FIRMWARE CURRENT WATCHDOG (200Hz) ---
         // Last line of defense: if any motor exceeds the hard limit,
         // immediately disable all motors regardless of GUI state.
         const float CURRENT_LIMIT_A = 3.0;  // Amps — matches GUI config
         if (motors_enabled) {
             for (int i = 0; i < 4; i++) {
                 if (fabsf(actual_current[i]) > CURRENT_LIMIT_A) {
                     motors_enabled = false;
                     set_motor_state(ID_LEFT_1, false);
                     set_motor_state(ID_LEFT_2, false);
                     set_motor_state(ID_RIGHT_1, false);
                     set_motor_state(ID_RIGHT_2, false);
                     for (int j = 0; j < 4; j++) {
                         target_pos[j] = actual_pos[j];
                         last_sent_pos[j] = -9999.0;
                     }
                     break;  // Motors disabled, exit check
                 }
             }
         }

         // --- SOFTWARE FAILSAFE: Sensor State Override ---
         if (!imu_healthy && motors_enabled) {
             motors_enabled = false;
         }

         // --- Motor Control ---
         if (motors_enabled) {
             pack_and_send_pos_speed(ID_LEFT_1, target_pos[0], target_speed[0]);
             pack_and_send_pos_speed(ID_LEFT_2, target_pos[1], target_speed[1]);
             pack_and_send_pos_speed(ID_RIGHT_1, target_pos[2], target_speed[2]);
             pack_and_send_pos_speed(ID_RIGHT_2, target_pos[3], target_speed[3]);
             for(int i=0; i<4; i++) last_sent_pos[i] = target_pos[i];
         } else {
             set_motor_state(ID_LEFT_1, false); set_motor_state(ID_LEFT_2, false);
             set_motor_state(ID_RIGHT_1, false); set_motor_state(ID_RIGHT_2, false);
             for(int i=0; i<4; i++) {
                 target_pos[i] = actual_pos[i];
                 last_sent_pos[i] = -9999.0;
             }
         }

         // --- IMU Read ---
         readAllIMUs();

         // --- Publish Extended Feedback ---
         // [0..3] motor positions, [4..7] motor currents, [8] CAN count,
         // [9..11] IMU1 accel XYZ, [12..14] IMU2, [15..17] IMU3, [18..20] IMU4
         msg_feedback.data.size = 21;
         for(int i=0; i<4; i++) msg_feedback.data.data[i]   = actual_pos[i];
         for(int i=0; i<4; i++) msg_feedback.data.data[4+i] = actual_current[i];
         msg_feedback.data.data[8] = (double)can_rx_count;
         for(int imu=0; imu<4; imu++) {
             for(int ax=0; ax<3; ax++) {
                 msg_feedback.data.data[9 + imu*3 + ax] = (double)imu_accel[imu][ax];
             }
         }
         RCSOFTCHECK(rcl_publish(&feedback_pub, &msg_feedback, NULL));
      }
      break;
    case AGENT_DISCONNECTED:
      destroy_entities();
      state = WAITING_AGENT;
      break;
  }
}

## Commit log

2026-05-12 Add files with Git LFS tracking for large binaries
    [010-10-120 bearing-jntes.SLDASM, 010-10-120 bearing.SLDASM, 010-10-120 inner ring-jntes.SLDPRT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]
2026-06-01 Remove obsolete docs; add lower mechanism report
    Clean up repository by deleting multiple outdated General/ files. Add a new Robot Mechanism (Lower) Detailed Report.docx to consolidate and replace legacy documentation.
    [Understanding Needs.xlsx]
2026-06-01 Refactor code structure for improved readability and maintainability
    [Gantt Chart.xlsx, Project Plan 2026.xlsx, Understanding Needs.xlsx]
2026-06-02 Add Teensy Firmware V5 with I²C timeout and sensor state failsafe (added electronics handover docs)
    [Clamping lever eccentrical cam w internal thread (clamped).csv, Clamping lever eccentrical cam w internal thread (clamped).stp]
2026-06-02 Cleaned up/organized folders for better wayfinding
    [010-10-120 bearing-jntes.SLDASM, 010-10-120 bearing.SLDASM, 010-10-120 inner ring-jntes.SLDPRT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]
